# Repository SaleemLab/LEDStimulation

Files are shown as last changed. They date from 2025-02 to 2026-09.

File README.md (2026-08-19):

# Full-Field LED Visual Stimulator

An open-source, high-precision visual stimulation platform designed for visual neuroscience, sensory physiology, and human psychophysics. The system delivers temporally agile, multi-chromatic optical stimulation (e.g., Green for M-cones/rods and UV for S-cones, or custom multi-spectral arrays) with sub-millisecond precision.

https://github.com/user-attachments/assets/08af2269-a270-4899-ae75-62786a714254

*Example stimulus: 2 Hz antiphase (Green / UV) sinusoidal flicker.*

---

## Key Capabilities

- **High-Resolution Temporal Modulation:** 16-bit Phase-Correct carrier PWM (~7.68–10 kHz) combined with hardware-interrupt pacing (Timer3 CTC ISR) eliminates visible digital stepping and software loop jitter.
- **Rich Stimulus Battery:** Native microsecond-timed generation of sinusoidal flickers, Gaussian white noise (with Central Limit Theorem PRNG), contrast-switching adaptation sequences, exponential frequency chirps, and stepped luminance pulses.
- **Quantitative Radiometric Calibration:** End-to-end MATLAB calibration pipeline mapping raw duty cycles to linearized lookup tables (LUTs) and calculating exact photoreceptor isomerisation rates ($R^*/\text{photoreceptor/s}$).
- **Flexible Form Factors:** Supports both 200mm full-field panel enclosures (with magnetic diffusion clamping) and miniature wearable mounts for Pupil Labs Neon eye-tracking glasses.
- **Reactive Experiment Orchestration:** Full integration with [Bonsai](https://bonsai-rx.org/) for closed-loop, state-dependent, adaptive psychometric staircase, and LabStreamingLayer (LSL) multi-modal recording.

---

## System Architecture

```mermaid
graph LR
    subgraph Host Software
        Bonsai[Bonsai Reactive Workflows]
        LSL[LabStreamingLayer / LabRecorder]
        MATLAB[MATLAB Calibration Suite]
    end

    subgraph Microcontroller Firmware
        MCU[Arduino Leonardo / Teensy 4.1]
        T1[Timer1: 16-bit PWM]
        T3[Timer3: CTC Interrupt Pacing]
        LUT[PROGMEM Gamma LUT]
    end

    subgraph Hardware & Optics
        Driver[Multi-Channel Driver Stage]
        LEDs[Dual-Channel LED Arrays]
        Enclosure[Magnetic Diffusion Enclosure / Glasses]
        Sensors[Photodiode / Power Meter / Eye Tracker]
    end

    Bonsai -- Serial ASCII (115200) --> MCU
    MATLAB -. Offline Calibration .-> LUT
    MCU --> T1 & T3
    T3 --> LUT --> T1
    T1 --> Driver --> LEDs --> Enclosure
    Enclosure -. Optical Feedback .-> Sensors
    Sensors --> LSL
```

---

## Quickstart Guide

### 1. Flash the Firmware
1. Open [`ArduinoCode/StimulusControlViaSerial_Leonardo_v8/StimulusControlViaSerial_Leonardo_v8.ino`](file:///d:/Code/LEDStimulation/ArduinoCode/StimulusControlViaSerial_Leonardo_v8/StimulusControlViaSerial_Leonardo_v8.ino) in the Arduino IDE.
2. Select **Arduino Leonardo** as your board and choose the corresponding COM port.
3. Click **Upload**.

### 2. Connect Hardware & Verify
1. Connect your LED driver to the designated MCU pins (PWM: Pins 9 & 10; Indicators: Pins 4 & 5).
2. Open the Serial Monitor at `115200` baud.
3. Send a test sinusoidal flicker:
   ```text
   s, 3000, 2.0, 0.0, 0.5, 0.8, 0.8
   ```
   *(Runs a 3-second, 2 Hz antiphase flicker on Channels A and B at 80% contrast).*

### 3. Launch Experimental Workflows
Open [Bonsai](https://bonsai-rx.org/) and load one of the pre-built visual stimulation workflows from [`BonsaiCode/`](file:///d:/Code/LEDStimulation/BonsaiCode/) (e.g., `LEDstimulation_normal.bonsai` or `ManualMethodOfAdjustment.bonsai`).

---

## Documentation Index

Comprehensive guides, schematics, and technical specifications are available in the **[`docs/`](docs/index.md)** directory:

| Section | Description |
| :--- | :--- |
| **[1. Hardware](docs/1-hardware/circuit-and-driver.md)** | [Circuit & Driver](docs/1-hardware/circuit-and-driver.md) • [Custom PCBs](docs/1-hardware/custom-pcbs.md) • [Panel Enclosure](docs/1-hardware/enclosure-and-optics/panel-enclosure.md) • [Wearable Glasses](docs/1-hardware/enclosure-and-optics/wearable-glasses.md) • [Bill of Materials](docs/1-hardware/bill-of-materials.md) |
| **[2. Firmware](docs/2-firmware/architecture-and-timers.md)** | [Architecture & Hardware Timers](docs/2-firmware/architecture-and-timers.md) • [Serial API Reference](docs/2-firmware/serial-api-reference.md) • [Firmware Variants](docs/2-firmware/firmware-variants.md) |
| **[3. Calibration](docs/3-calibration/calibration-guide.md)** | [Calibration Guide](docs/3-calibration/calibration-guide.md) • [Gamma LUT Pipeline](docs/3-calibration/gamma-lut-pipeline.md) • [Photoreceptor Calculations](docs/3-calibration/photoreceptor-calculations.md) |
| **[4. Experimental Workflows](docs/4-experimental-workflows/bonsai-overview.md)** | [Bonsai Setup](docs/4-experimental-workflows/bonsai-overview.md) • [Stimulation Paradigms](docs/4-experimental-workflows/stimulation-paradigms.md) • [Integration & Multi-Modal Sync](docs/4-experimental-workflows/integration-and-sync.md) |
| **[5. Reference](docs/5-reference/performance-and-sync.md)** | [Performance Characteristics, Switching Dynamics & Thermal Notes](docs/5-reference/performance-and-sync.md) |

---

## Repository Structure

```text
├── ArduinoCode/                  # Microcontroller firmware (Leonardo v8, DDS, Teensy 4.1, IMU)
├── BonsaiCode/                   # Main Bonsai visual reactive workflows & stimulus CSVs
├── BonsaiForHumanExperiments/    # Dedicated human psychophysics Bonsai workflows
├── Calibration/                  # MATLAB scripts for radiometry, gamma LUTs & opsin calculations
├── Hardware/                     # CAD files (.stp, .stl, .ipt), KiCad PCB designs & driver schematics
│   ├── Enclosure/                # Baseplate CAD & 3D printed magnetic diffusion clamps
│   ├── glasses/                  # Pupil Labs Neon glasses boom arm & miniature diffuser
│   ├── LED_board/                # KiCad dual-channel LED array PCB
│   └── LED_board_humans/         # KiCad 3-colour LED array PCB (WIP redesign with layout improvements)
├── HumanExpAnalysis/             # MATLAB scripts for IMU movement and behavioural analysis
├── LabRecorderFiles/             # Multi-modal LabStreamingLayer (LSL) recording configurations
└── docs/                         # Modular technical documentation
```

---

## License & Attribution

Developed for scientific research applications. If you use this platform in your research, please cite this repository.

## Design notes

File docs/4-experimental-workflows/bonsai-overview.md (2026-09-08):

# Bonsai Workflow Overview

[Bonsai](https://bonsai-rx.org/) is an open-source visual reactive programming environment used here to coordinate experiment state, stream serial commands to the microcontroller, record behavioural sensors, and synchronize multi-modal data streams.

!!! note "Work in Progress"
    This documentation section is currently a work in progress.

---

## 1. Environment Setup

* **Bonsai Version:** Compatible with Bonsai 2.7.x / 2.8.x.
* **Required Package Dependencies:**
  * `Bonsai.Core` & `Bonsai.Design`
  * `Bonsai.System` (IO & Serial Ports)
  * `Bonsai.Arduino`
  * `Bonsai.Dsp` & `Bonsai.Numerics`
  * `Bonsai.Shaders` / `Bonsai.Vision` *(for display/camera workflows)*
  * `Bonsai.LabStreamingLayer` *(for LSL multi-modal stream synchronization)*

---

## 2. Solution Structure

Located in [`BonsaiCode/`](file:///d:/Code/LEDStimulation/BonsaiCode/):
* `BonsaiCode.sln` / `Extensions.csproj` — C# extensions for custom Bonsai data processing nodes.
* `.bonsai/` — Package configuration and local environment dependencies.
* `*.bonsai` & `*.bonsai.layout` — Visual workflow definitions and GUI layout arrangements.
* `StimulusCSVfiles/` — Pre-defined stimulus parameter tables and trial condition matrices.

---

## 3. Core Workflow Architecture

```mermaid
flowchart TD
    subgraph TX["1. Stimulus Command Generation & Dispatch"]
        direction LR
        Timer["<b>Trial Trigger</b><br/>Timer or Sync Pulse"]
        Select["<b>Trial Matrix</b><br/>Row from CSV Table"]
        Format["<b>ASCII Formatter</b><br/>Format Serial String"]
        Write["<b>Bonsai SerialPort</b><br/>Non-blocking Dispatch"]
        Timer --> Select --> Format --> Write
    end

    subgraph RX["2. Device Execution & Data Recording"]
        direction LR
        USB["<b>MCU Execution</b><br/>ATmega32U4 / Teensy"]
        Read["<b>Serial Feedback</b><br/>Status / Confirmation"]
        Log["<b>Data Acquisition</b><br/>CSV / LSL Log Streams"]
        USB --> Read --> Log
    end

    Write ==>|Serial ASCII (115200)| USB
```

* **Serial Communication Node:** Configured for the microcontroller's COM port at `115200` baud.
* **Non-Blocking Execution:** Serial commands are dispatched asynchronously, allowing the host PC to continuously stream eye-tracking video, IMU data, or digital sync markers without dropped frames.

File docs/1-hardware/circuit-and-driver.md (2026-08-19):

# Circuit & Driver Design

This section describes the electronic drive circuitry used to power and modulate the optical LED loads in the stimulator.

!!! note "Single-Channel vs. Multi-Channel Scaling"
    The schematics below illustrate the driver circuit for **a single optical channel / colour**. To drive multi-channel systems (e.g., dual-colour or 3-colour arrays), **replicate the circuit for each channel**, connecting each to an independent microcontroller PWM pin (e.g., separate timer outputs). All channels share the common power rails ($+12\,\text{V}$ and GND), while their switching paths and PWM control lines remain independent.

---

## 1. Direct Microcontroller PWM Drive (Base Configuration)

The simplest driving topology connects a single microcontroller PWM output pin directly to an LED load through a series combination of a fixed current-limiting resistor and a multi-turn cermet variable resistor. This direct-drive topology works when the LED load has voltage ($V_f$) and current ($I_{\text{LED}}$) requirements that fall *well* within the direct drive capability of the microcontroller GPIO pins (typically $V_{\text{pin}} \le 5\text{V}$, $I_{\text{max}} \le 20\text{--}40\text{ mA}$).

Simple Direct PWM LED Circuit

* **`PWM Source`:** Outputs a high-frequency PWM carrier providing temporal stimulus patterns for one channel (replicate circuit and use additional PWM pins for multi-colour setups).
* **$R_{\text{fixed}}$ (Current Limiter):** Sets the absolute maximum current ceiling to protect both the microcontroller output pin and LED load from overcurrent when $R_{\text{var}} = 0\,\Omega$.
* **$R_{\text{var}}$ (Cermet Trimpot):** Allows manual analog adjustment of maximum forward current and luminance. Using a **cermet** (ceramic-metal thick-film) trimpot is critical for high-frequency PWM visual stimulation. Alternative potentiometer constructions will degrade or disrupt the stimulus.

---

## 2. Low-Side NPN Transistor Switching Drive (12V / Multi-LED Arrays)

When driving multi-LED series strings or larger arrays that exceed microcontroller GPIO limits ($5\,\text{V}$ and $20\text{--}40\,\text{mA}$), an external DC power supply (typically $+12\,\text{V}$) is used with a low-side NPN bipolar junction transistor (BJT) switch.

Low-Side Transistor LED Circuit

*Figure: Low-side switching circuit for a single colour channel. For multi-channel arrays, replicate the transistor, base resistor, trimpot, and LED strings for each channel while sharing the $+12\,\text{V}$ rail and Common Ground.*

* **`+12V Supply` & Multiple LED Lines:** Powers one or more parallel lines of 3 series LEDs ($V_f \approx 6.3\text{--}9.9\,\text{V}$ per string), leaving optimal voltage headroom from the $12\,\text{V}$ rail.
* **$R_{\text{fixed}}$ (Per-Line Current Limiter):** Each parallel LED line includes its own fixed series resistor to limit and balance current across individual branches.
* **$R_{\text{var}}$ (Master Cermet Trimpot):** A single shared cermet trimpot on the merged return path controls the maximum current and luminance for all parallel lines belonging to **this channel**.
* **NPN Transistor (Low-Side Switch):** General-purpose small-signal NPN transistor (e.g., **onsemi 2N3904**, rated for $40\,\text{V}$, $200\,\text{mA}$, 3-pin TO-92 package). Sinks the combined load current for this channel to ground when switched ON by the PWM signal (ensure total channel current across parallel strings remains $\le 200\,\text{mA}$).
* **`PWM Source`, $R_{\text{base}}$ & $R_{\text{pull-down}}$:** An MCU PWM pin switches the transistor through a base resistor ($R_{\text{base}} \approx 100\,\Omega$). A pull-down resistor ($R_{\text{pull-down}} = 10\,\text{k}\Omega$) keeps the base pulled to $0\,\text{V}$ during microcontroller startup or floating states.
* **Common Ground:** The Arduino ground and the external $12\,\text{V}$ power supply ground **must be connected together** to establish the shared $0\,\text{V}$ reference required for the base-emitter voltage ($V_{BE} \approx 0.7\,\text{V}$) to switch the transistor reliably.
* **Multi-Channel Operation:** To drive a 2nd or 3rd colour channel independently, duplicate the transistor stage ($Q_1, R_{\text{base}}, R_{\text{var}}$) and connect its base to a 2nd MCU PWM pin (e.g. Pin 9 and Pin 10 on Arduino Uno / Nano). All channels share the $+12\,\text{V}$ power rail and system Ground.

---

## 3. Physical Circuit & Bench Implementation

Physical Circuit Bench Setup
*Figure: Benchtop driver circuit implementation showing Arduino microcontroller, multi-turn cermet trimpot, transistor switching stage, and wiring harness connected to LED array.*

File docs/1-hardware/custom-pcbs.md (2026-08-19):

# Custom PCBs

This page documents the custom PCBs designed in KiCad for multi-wavelength LED stimulation and driver interfacing.

---

## 1. Standard LED Array Board (`LED_board`)

* **Location:** [`Hardware/LED_board/`](file:///d:/Code/LEDStimulation/Hardware/LED_board/) | **Status:** **Active**
* **Files:** `LED_board.kicad_sch`, `LED_board.kicad_pcb`, `LED_board.step`, `production/`
* **Acknowledgements:** Board is based on an earlier prototype designed by Andre Maia Chagas.

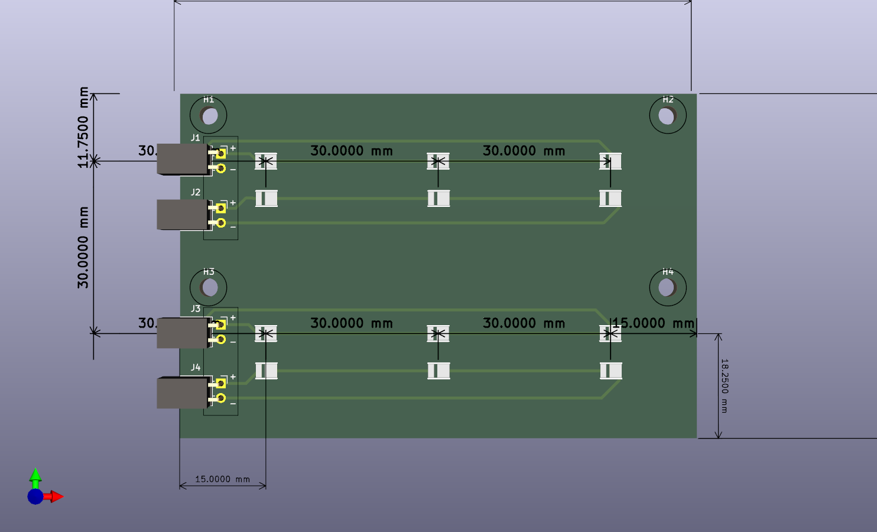
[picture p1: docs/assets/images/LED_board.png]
Standard LED Array Board Render

*Figure: KiCad 3D layout of standard dual-channel LED array board with dimensions and grid pitch.*

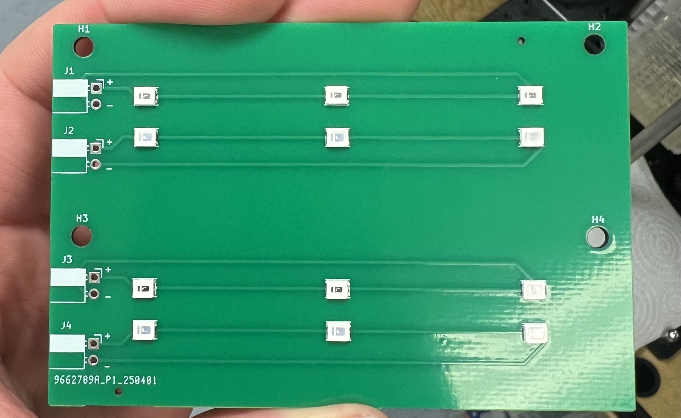
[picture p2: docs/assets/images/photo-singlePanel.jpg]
Single Assembled PCB

*Figure: Assembled dual-channel LED array PCB showing the 4 LED lines, solder pads for J1–J4, and mounting holes H1–H4.*

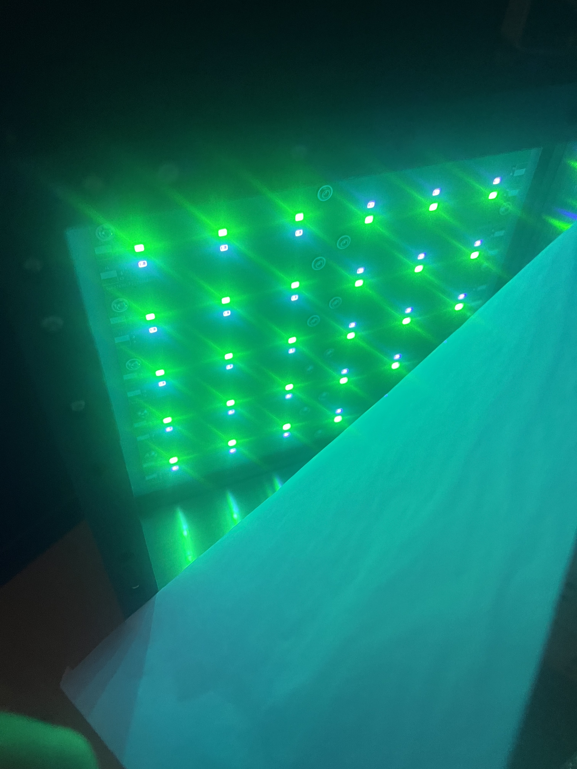
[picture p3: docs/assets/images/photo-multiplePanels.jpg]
Multiple Tiled Panels in Operation

*Figure: Multiple tiled LED boards mounted inside the panel enclosure and illuminated beneath the optical diffuser sheet.*

### Design & Current Implementation

The board provides wide-field visual stimulation using multiple equally-spaced LED lines:

* **Layout:** 4 lines of LEDs (2 lines per colour, interleaved), with 3 series LEDs per line (12 LEDs total, running at $+12\,\text{V}$).
* **Spacing:** $3\,\text{cm}$ ($30\,\text{mm}$) pitch between lines, matching the spacing across adjacent tiled boards.
* **Mounting:** Through-holes for M3 standoffs to attach securely to the aluminium backplate / heatsink.
* **Connectors:** 4 separate 2-pin ($2.54\,\text{mm}$) headers — one dedicated connector per LED line (8 wires total per board back to the driver). Headers can be straight or right-angled, and can be mounted on the **front or reverse side** of the PCB to route cables cleanly out the back of the backplate.
* **Current Limiting:** External (requires off-board resistors on the driver board).

### Future Improvements

* **On-Board SMD Resistors:** Add dedicated surface-mount ballast resistors (1206 footprint) on each line to balance branch currents directly on the PCB and eliminate off-board resistors.
* **Single Consolidated Connector:** Replace the 4 separate 2-pin headers with a single multi-pin connector (e.g. 4-pin JST-XH). A common $+12\,\text{V}$ anode rail powers all lines, branching into separate low-side return paths per colour for independent PWM modulation (reducing wiring from 8 to 3–4 wires).
* **Modular Daisy-Chaining:** Add pass-through edge connectors so arbitrary boards can be tiled together with parallel electrical connections, preserving the $3\,\text{cm}$ pitch without extra cable runs.

---

## 2. Experimental & In-Development Boards

### 3-Colour LED Array Board (`LED_board_humans`)
* **Location:** [`Hardware/LED_board_humans/`](file:///d:/Code/LEDStimulation/Hardware/LED_board_humans/) | **Status:** ⚠️ **WIP**
* Experimental 3-channel (3-colour) panel redesign with optimized routing. *(Note: Unrelated to the wearable glasses setup).*

### Constant Current Driver Board (`Constant_current_driver`)
* **Location:** [`Hardware/Constant_current_driver/`](file:///d:/Code/LEDStimulation/Hardware/Constant_current_driver/) | **Status:** ⚠️ **WIP (Inactive)**
* Prototype driver board. Current setups use the low-side transistor circuit described in [Circuit & Driver Design](file:///d:/Code/LEDStimulation/docs/1-hardware/circuit-and-driver.md).

---

## 3. Fabrication

Gerber files and drill maps are in the respective `production/` directories, ready for fabrication (e.g. JLCPCB, PCBWay).

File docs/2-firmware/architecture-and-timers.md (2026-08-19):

# Firmware Architecture & System Principles

The visual stimulation platform utilizes bare-metal microcontroller firmware to deliver sub-millisecond temporal precision, high carrier frequencies, and artifact-free luminance modulation.

We use primarily the **Arduino Leonardo (ATmega32U4 @ 16 MHz)**, which possesses several hardware properties that make it well suited for high-precision optical stimulation:

* **Native USB Communication (CDC):** The ATmega32U4 features native on-chip USB communication, avoiding the transfer latency, buffer bloat, and jitter introduced by external USB-to-UART bridge chips (e.g., FTDI / CH340).
* **Deterministic 16-bit Timer Registers:** Direct bare-metal control of hardware `Timer1` allows 31.25 kHz Phase Correct PWM with cycle-accurate register writes (`OCR1A`, `OCR1B`).
* **Sub-Microsecond Timing Determinism:** Without an underlying RTOS or thread scheduler, interrupt service routines execute with sub-microsecond predictability.
* **Cost & Accessibility:** Standardized, open-source form factor that is cost-effective and readily replicable across research laboratories.

Other microcontrollers can also be used if higher bit-depth, clock speed, or sample rates are desired—such as the **PJRC Teensy 4.1 (ARM Cortex-M7 @ 600 MHz)**, for which a 12-bit, 36.62 kHz DDS implementation ([`LEDStimController_Teensy41_DDS.ino`](file:///d:/Code/LEDStimulation/ArduinoCode/LEDStimController_Teensy41_DDS/LEDStimController_Teensy41_DDS.ino)) is provided.

The primary canonical firmware is **[`StimulusControlViaSerial_Leonardo_DDS_8bit_2freq.ino`](file:///d:/Code/LEDStimulation/ArduinoCode/StimulusControlViaSerial_Leonardo_DDS_8bit_2freq/StimulusControlViaSerial_Leonardo_DDS_8bit_2freq.ino)**, implementing a **Direct Digital Synthesis (DDS)** engine running at a **31.25 kHz** carrier frequency.

---

## 1. Canonical System Architecture (`DDS_8bit_2freq`)

The canonical firmware synchronizes carrier PWM generation and stimulus waveform synthesis at **31.25 kHz** using Direct Digital Synthesis (DDS).

* **Command Ingestion:** ASCII commands received over USB Serial at 115200 baud are parsed and configured into stimulus state parameters (frequencies, phases, contrasts, durations).
* **High-Frequency Carrier:** Hardware `Timer1` generates a 31.25 kHz Phase Correct PWM carrier on Pin 9 (Channel A) and Pin 10 (Channel B).
* **Synchronous Interrupt Pacing:** The `TIMER1_OVF_vect` interrupt fires synchronously on every PWM cycle at 31.25 kHz ($32\ \mu\text{s}$ period), invoking a dynamic callback function pointer (`timer1Callback`).
* **DDS Waveform Synthesis:** The 32-bit phase accumulators advance each cycle, indexing into a 256-sample sine wavetable, and applying raised cosine onset/offset envelopes or contrast envelopes.
* **Optical Linearization:** The calculated luminance index is mapped through Flash-resident (`PROGMEM`) gamma Look-Up Tables before being written directly to `OCR1A` and `OCR1B`.

---

## 2. Core Architectural Principles

### 2.1. Direct Digital Synthesis (DDS) Engine

Rather than stepping through a wavetable with variable timer interrupts, the DDS engine uses **32-bit fixed-point phase accumulators** updated at every single PWM carrier cycle ($31.25\text{ kHz}$):

$$\Delta\theta = \text{round}\left(f_{\text{stimulus}} \times \frac{2^{32}}{f_{\text{PWM}}}\right)$$

On an ATmega32U4 running at 16 MHz with a $31.25\text{ kHz}$ PWM carrier, the scaling constant is pre-computed with IEEE 754 precision:

$$\frac{2^{32}}{31250} = 137438.953125$$

```cpp
uint32_t calcPhaseInc(float freq) {
    // 4294967296.0 / 31250.0 = 137438.953125
    return (uint32_t)(freq * 137438.953125f + 0.5f);
}
```

* **Instantaneous Frequency & Phase Transitions:** Frequency changes require simply writing a new 32-bit phase increment value (`phaseIncrementA = calcPhaseInc(newFreq)`). There are zero phase discontinuities, zero timer reconfiguration delays, and no waveform glitches.
* **Wavetable Indexing:** The most significant byte of the 32-bit accumulator directly selects the sample from a 256-point sinusoidal wavetable:
  ```cpp
  uint8_t indexA = ((uint8_t*)&phaseAccumulatorA)[3]; // Instantaneous byte extraction
  ```

---

### 2.2. High-Frequency Carrier Generation & Timer1 PWM Configuration

`Timer1` on the ATmega32U4 is configured in **16-bit Phase Correct PWM mode (Mode 10)**. In this dual-slope mode, the timer counts continuously up from $0$ to `ICR1` (TOP) and then counts down from `ICR1` back to $0$.

The resulting PWM carrier frequency is given by:

$$f_{\text{PWM}} = \frac{f_{\text{CPU}}}{2 \times N \times \text{TOP}}$$

For a target frequency of $31.25\text{ kHz}$ with a $16\text{ MHz}$ CPU clock, the prescaler is $N = 1$ and $\text{TOP} = 256$:

$$f_{\text{PWM}} = \frac{16\text{ MHz}}{2 \times 1 \times 256} = 31.25\text{ kHz}$$

* **Elimination of Saccadic CFF Artifacts:** The Critical Flicker Fusion (CFF) threshold in rodents and primates is typically $< 60-100\text{ Hz}$. Operating at $31.25\text{ kHz}$ guarantees that rapid eye movements or micro-saccades can never visually resolve carrier switching.
* **Photodiode & Recording Immunity:** High-speed electrophysiological amplifiers and photodiodes are immune to carrier ringing at $31.25\text{ kHz}$.
* **Acoustic Silence:** Prevents audible coil whine from inductors or ceramic capacitors in the driver circuitry.

#### Step 1: Calculating Prescaler and TOP

The firmware calculates the optimal prescaler ($N \in \{1, 8, 64, 256, 1024\}$) and `TOP` value dynamically to maximize bit-depth resolution:

```cpp
long calculatePrescalerAndTOP(long desiredFrequency, long &prescaler) {
  long TOP = 0;
  long possiblePrescalers[] = { 1, 8, 64, 256, 1024 };

  for (int i = 0; i < 5; i++) {
    long currentPrescaler = possiblePrescalers[i];
    long calculatedTOP = (CLOCK_FREQ / (2 * currentPrescaler * desiredFrequency));

    if (calculatedTOP >= 0 && calculatedTOP <= 65535) {
      prescaler = currentPrescaler;
      TOP = calculatedTOP;
      break;  // Select the smallest valid prescaler for maximum resolution
    }
  }
  return TOP;
}
```

For $31250\text{ Hz}$, the algorithm selects `prescaler = 1` and `TOP = 256` ($8\text{-bit}$ resolution).

#### Step 2: Register-Level Timer1 Setup

The `configureTimer1()` function directly writes to the ATmega32U4 control registers (`TCCR1A`, `TCCR1B`, `ICR1`):

```cpp
void configureTimer1(long prescaler, long TOP) {
  // Reset Timer1 control registers
  TCCR1A = 0;
  TCCR1B = 0;

  // Enable non-inverting PWM output on Pin 9 (OC1A) and Pin 10 (OC1B)
  TCCR1A |= (1 << COM1A1);  
  TCCR1A |= (1 << COM1B1);  

  // Configure Phase Correct PWM with ICR1 as TOP (Mode 10)
  TCCR1B |= (1 << WGM13);   
  TCCR1B &= ~(1 << WGM12);  
  TCCR1A &= ~(1 << WGM11);  
  TCCR1A &= ~(1 << WGM10);  

  // Apply clock prescaler
  switch (prescaler) {
    case 1:    TCCR1B |= (1 << CS10); break;               // Prescaler = 1 (No division)
    case 8:    TCCR1B |= (1 << CS11); break;               // Prescaler = 8
    case 64:   TCCR1B |= (1 << CS11) | (1 << CS10); break; // Prescaler = 64
    case 256:  TCCR1B |= (1 << CS12); break;               // Prescaler = 256
    case 1024: TCCR1B |= (1 << CS12) | (1 << CS10); break; // Prescaler = 1024
  }

  // Set the TOP counter limit (ICR1 = 256)
  ICR1 = TOP;
}
```

* `COM1A1` & `COM1B1`: Enable non-inverting compare mode on OC1A (Pin 9) and OC1B (Pin 10). The pin clears on compare match when counting up, and sets on compare match when counting down.
* `WGM13 = 1` (with `WGM12=0`, `WGM11=0`, `WGM10=0`): Sets dual-slope Phase Correct PWM with `ICR1` acting as the TOP limit.
* `CS10 = 1`: Connects the 16 MHz system clock directly without prescaling ($N=1$).
* `ICR1 = 256`: Establishes the peak counter value.

#### Step 3: Fast Inline Output Writes

Luminance duty cycles are updated by writing directly to `OCR1A` and `OCR1B`, reading calibrated values from `PROGMEM` Flash tables:

```cpp
__attribute__((always_inline)) inline void setChA(uint8_t ocrValue) {
  OCR1A = pgm_read_byte_near(currentChALUT + ocrValue);
}

__attribute__((always_inline)) inline void setChB(uint8_t ocrValue) {
  OCR1B = pgm_read_byte_near(currentChBLUT + ocrValue);
}
```

#### Step 4: Synchronous Interrupt Coupling (`TIMER1_OVF_vect`)

In Phase Correct PWM mode, the timer overflow interrupt flag (`TOV1`) is set every time the counter reaches bottom ($0$). The firmware uses this interrupt to synchronously trigger the DDS waveform synthesis at $31.25\text{ kHz}$:

```cpp
void (*timer1Callback)() = nullptr;  

void setTimer1Callback(void (*callback)()) {
  timer1Callback = callback;
}

void startTimer1Interrupt() {
  TIFR1 |= (1 << TOV1);     // Clear any pending overflow flag
  TIMSK1 |= (1 << TOIE1);   // Enable Timer1 Overflow Interrupt
}

void stopTimer1Interrupt() {
  TIMSK1 &= ~(1 << TOIE1);  // Disable Timer1 Overflow Interrupt
}

ISR(TIMER1_OVF_vect) {
  if (timer1Callback) {
    timer1Callback();       // Executes DDS synthesis at 31.25 kHz
  }
}
```

---

### 2.3. Dual Independent Channels & Frequencies

`StimulusControlViaSerial_Leonardo_DDS_8bit_2freq` maintains independent 32-bit phase accumulators and phase increments for Channel A and Channel B:

* **Dichoptic Stimulation:** Present distinct frequencies simultaneously to each eye (e.g., $5\text{ Hz}$ on Left Eye, $7\text{ Hz}$ on Right Eye).
* **Chromatic & Dual-Wavelength Probing:** Drive Green ($530\text{ nm}$) and UV ($395\text{ nm}$) LEDs with independent phase relationships ($0^\circ$ in-phase vs. $180^\circ$ antiphase) and independent contrast levels.

---

### 2.4. Raised Cosine Temporal Windowing (Fade In/Out)

Sudden rectangular onsets of bright visual flicker can trigger retinal startle responses and severe transient visual evoked potentials (VEPs).

The firmware applies a smooth **Modular Raised Cosine Temporal Window** (default $100\text{ ms}$):

* A 64-entry pre-computed envelope table (`raisedCosineLUT[64]`) scales the contrast from $0 \to 100\%$ at stimulus onset and $100\% \to 0$ at stimulus offset.
* A 32-bit addition accumulator (`fadePhase += envStep`) steps through the envelope table without runtime multiplication or floating-point trigonometry.

---

### 2.5. Jitter Elimination & USB Heartbeat Suppression

Under normal Arduino operation, the USB Start-of-Frame (SOF) interrupt fires every $1.0\text{ ms}$, and `Timer0` fires every $1.024\text{ ms}$ for `millis()`. These interrupts cause microsecond-scale jitter and cumulative timing drift ($\approx 10.5\text{ ms}$ slip over long trials).

During active stimulation, the firmware temporarily suppresses these interrupts:

```cpp
TIMSK0 &= ~_BV(TOIE0);  // Disable Timer0 millis() interrupt
UDIEN &= ~(1 << SOFE);  // Disable USB Start-of-Frame interrupt
```

Upon trial completion, both interrupts are re-enabled, ensuring zero timing slip during stimulation while retaining full USB communication.

---

### 2.6. Lock-Free Atomic Synchronization

To avoid global interrupt blocking (`cli()` / `sei()`) that could introduce carrier jitter, the firmware uses a double-read atomic pattern to safely read multi-byte cycle counters between the main loop and ISR:

```cpp
uint32_t safeCycles1, safeCycles2;
do {
    safeCycles1 = completedCycles;
    safeCycles2 = completedCycles;
} while (safeCycles1 != safeCycles2);
```

---

## 3. Sinewave Trial Execution Lifecycle (End-to-End Walkthrough)

When host software (e.g. Bonsai or Python) requests a sinusoidal flicker trial, the firmware executes a precise sequence across serial ingestion, parameter arming, interrupt-driven synthesis, and completion handshake.

```
[Host PC]  -- "s,5000,4.0,4.0,0.0,0.5,0.8,0.8\r" -->  [Serial Parser]
                                                              |
                                                    [outputSinewave()]
                                                    (Arm DDS, Phase, Fade)
                                                              |
                                            [Disable Timer0 & USB SOF]
                                            [Attach Timer1 OVF Callback]
                                                              |
                                          [31.25 kHz sinewaveInterrupt()]
                                          (DDS step, Fade, LUT, OCR1A/B)
                                                              |
                                           [Target Interrupts Reached]
                                                              |
                                            [Restore Interrupts & Pins]
[Host PC]  <------------- "-1\n" Handshake ----------- [Serial Print]
```

### Step 1: Serial Command Ingestion & Parsing

The main `loop()` continuously monitors incoming characters over USB CDC:

```cpp
void loop() {
  GetSerialInput();
  if (newData) {
    newData = false;
    ActionSerial();
  }
}
```

When a carriage return (`\r`) is received, `ActionSerial()` tokenizes the comma-separated ASCII string:

```cpp
// Example input: "s, 5000, 4.0, 4.0, 0.0, 0.5, 0.8, 0.8"
if (strcmp(FirstChar, "s") == 0) {
  long stimulusDuration = atof(serialVals[1]); // Duration (ms)
  float freqA = atof(serialVals[2]);           // Channel A Frequency (Hz)
  float freqB = atof(serialVals[3]);           // Channel B Frequency (Hz)
  float phaseA = atof(serialVals[4]);         // Channel A Starting Phase (0.0-1.0)
  float phaseB = atof(serialVals[5]);         // Channel B Starting Phase (0.0-1.0)
  float contrastA = atof(serialVals[6]);      // Channel A Contrast (0.0-1.0)
  float contrastB = atof(serialVals[7]);      // Channel B Contrast (0.0-1.0)

  outputSinewave(freqA, freqB, stimulusDuration, phaseA, phaseB, contrastA, contrastB);
}
```

---

### Step 2: Pre-Computing Trial Parameters & Arming the Hardware

Inside `outputSinewave()`, parameters are converted into fast integer representations before starting interrupts:

```cpp
void outputSinewave(float freqA, float freqB, long duration, float phaseA, float phaseB, float contrastA, float contrastB) {
  // 1. Convert phase offsets (0.0-1.0) to full 32-bit phase accumulator starting values
  phaseAccumulatorA = (uint32_t)(phaseA * 4294967296.0);
  phaseAccumulatorB = (uint32_t)(phaseB * 4294967296.0);

  // 2. Scale contrast floats (0.0-1.0) to 8-bit integer multipliers (0-255)
  contrastMultIntA = (uint16_t)(contrastA * 255.0);
  contrastMultIntB = (uint16_t)(contrastB * 255.0);

  // 3. Compute 32-bit DDS phase increments for both channels
  phaseIncrementA = calcPhaseInc(freqA);
  phaseIncrementB = calcPhaseInc(freqB);

  // 4. Calculate total PWM carrier cycles required for the requested trial duration
  targetTotalInterrupts = (unsigned long)((duration / 1000.0) * actualPWMFreq);

  // 5. Configure the 100ms Raised Cosine onset and offset fade boundaries
  float fadeTimeMs = FADE_DURATION_MS;
  if (fadeTimeMs > 0.0) {
    fadeInterrupts = (unsigned long)(actualPWMFreq * (fadeTimeMs / 1000.0));
    fadeOutStartInterrupt = targetTotalInterrupts - fadeInterrupts;
    envStep = (((uint32_t)FADE_LUT_MAX << 16) + fadeInterrupts - 1) / fadeInterrupts;
  }

  currentTick = 0;
  completedCycles = 0;
  fadePhase = 0;
  stimulusActive = true;

  // 6. Set channels to baseline mid-luminance (50% duty cycle)
  if (useChA) { setChA(MidLumi); }
  if (useChB) { setChB(MidLumi); }

  // 7. Drive hardware indicator pins HIGH (Pin 5 = Stimulus ON, Pin 4 = Frame/Cycle indicator)
  PORTC |= (1 << PORTC6); // Pin 5 HIGH
  PORTD |= (1 << PIND4);  // Pin 4 HIGH

  // 8. Temporarily disable Timer0 and USB SOF interrupts to prevent microsecond jitter
  TIMSK0 &= ~_BV(TOIE0);
  UDIEN &= ~(1 << SOFE);

  // 9. Attach the callback and start the 31.25 kHz Timer1 interrupt
  setTimer1Callback(sinewaveInterrupt);
  startTimer1Interrupt();

  // 10. Jitter-free wait loop (Main loop idles cleanly while ISR drives hardware)
  while (stimulusActive) {
    // Peacefully idle
  }

  // 11. Trial Teardown
  stopTimer1Interrupt();
  TIMSK0 |= _BV(TOIE0);   // Re-enable Timer0
  UDIEN |= (1 << SOFE);   // Re-enable USB SOF

  PORTD &= ~(1 << PIND4); // Pin 4 LOW
  PORTC &= ~(1 << PORTC6); // Pin 5 LOW

  // 12. Reset to baseline and send completion handshake
  if (useChA) { setChA(TopLumi / 2); }
  if (useChB) { setChB(TopLumi / 2); }
  delayMicroseconds(2000);
  Serial.print(F("-1\n"));
}
```

---

### Step 3: Synchronous Waveform Synthesis (`sinewaveInterrupt()` @ 31.25 kHz)

Every $32\ \mu\text{s}$, the Timer1 overflow interrupt triggers `sinewaveInterrupt()`. The entire routine executes in under $4\ \mu\text{s}$ using pure fixed-point arithmetic:

```cpp
void sinewaveInterrupt() {
  uint8_t currentEnvelope = 255;

  // 1. Calculate the active Raised Cosine fade envelope (Onset Ramp vs Steady State vs Offset Ramp)
  if (currentTick < fadeInterrupts) {
    fadePhase += envStep;
    uint16_t envIndex = fadePhase >> 16;
    if (envIndex > FADE_LUT_MAX) envIndex = FADE_LUT_MAX;
    currentEnvelope = raisedCosineLUT[envIndex];
  } else if (currentTick == fadeOutStartInterrupt) {
    fadePhase = 0;
    currentEnvelope = raisedCosineLUT[FADE_LUT_MAX];
  } else if (currentTick > fadeOutStartInterrupt) {
    fadePhase += envStep;
    uint16_t shiftPhase = fadePhase >> 16;
    uint16_t envIndex = (shiftPhase >= FADE_LUT_MAX) ? 0 : (FADE_LUT_MAX - shiftPhase);
    currentEnvelope = raisedCosineLUT[envIndex];
  }

  // 2. Track master elapsed clock and check for trial completion
  currentTick++;
  if (currentTick >= targetTotalInterrupts) {
    stimulusActive = false; // Signals the main loop to exit
  }

  // 3. Modulate requested contrast depth by the temporal envelope
  uint16_t effectiveContrastA = ((uint16_t)contrastMultIntA * (uint16_t)currentEnvelope) >> 8;
  uint16_t effectiveContrastB = ((uint16_t)contrastMultIntB * (uint16_t)currentEnvelope) >> 8;

  // 4. Advance 32-bit phase accumulators by the DDS phase increments
  uint32_t oldPhaseA = phaseAccumulatorA;
  phaseAccumulatorA += phaseIncrementA;
  phaseAccumulatorB += phaseIncrementB;

  // 5. Toggle Pin 4 on full cycle wrap-around to provide hardware cycle tracking
  if (phaseAccumulatorA < oldPhaseA) {
    completedCycles++;
    PIND = (1 << PIND4); // Hardware toggle Pin 4
  }

  // 6. Fast bitwise extraction of high byte for wavetable lookup (256 entries)
  uint8_t indexA = ((uint8_t*)&phaseAccumulatorA)[3];
  uint8_t indexB = ((uint8_t*)&phaseAccumulatorB)[3];

  // 7. Apply contrast depth around MidLumi (50% baseline)
  int16_t tempA = (int16_t)sineWaveTable[indexA] - (int16_t)MidLumi;
  int16_t ocrValA_calc = (int16_t)MidLumi + ((tempA * (int16_t)effectiveContrastA) >> 8);
  if (ocrValA_calc < 0) ocrValA_calc = 0;
  if (ocrValA_calc > 255) ocrValA_calc = 255;
  uint8_t ocrValA = (uint8_t)ocrValA_calc;

  int16_t tempB = (int16_t)sineWaveTable[indexB] - (int16_t)MidLumi;
  int16_t ocrValB_calc = (int16_t)MidLumi + ((tempB * (int16_t)effectiveContrastB) >> 8);
  if (ocrValB_calc < 0) ocrValB_calc = 0;
  if (ocrValB_calc > 255) ocrValB_calc = 255;
  uint8_t ocrValB = (uint8_t)ocrValB_calc;

  // 8. Lookup gamma-corrected register values and write directly to OCR1A and OCR1B
  if (useChA) { setChA(ocrValA); }
  if (useChB) { setChB(ocrValB); }
}
```

---

## 4. Additional Stimulus Engines (from v8 Firmware)

While the DDS firmware is the primary engine for smooth sinusoidal, frequency sweep, and contrast envelope stimulation, the **[`StimulusControlViaSerial_Leonardo_v8.ino`](file:///d:/Code/LEDStimulation/ArduinoCode/StimulusControlViaSerial_Leonardo_v8/StimulusControlViaSerial_Leonardo_v8.ino)** firmware provides specialized stochastic noise stimuli:

```mermaid
graph TD
    v8["StimulusControlViaSerial_Leonardo_v8<br><i>Stochastic Stimulus Engine</i>"]
    
    v8 --> WN["Gaussian White Noise ('wn')<br><i>xorshift32 PRNG + Central Limit Theorem</i>"]
    v8 --> FWN["Frozen White Noise ('fwn')<br><i>Reproducible PRNG Seed & Fixed Buffer</i>"]
    v8 --> CS["Contrast-Switching Noise ('cs')<br><i>2-State Alternating Gaussian Distribution</i>"]
```

### 4.1. Real-Time Gaussian White Noise (`wn`)

* **PRNG Engine (`xorshift32`):** Generates high-entropy 32-bit pseudo-random numbers in just 3 clock cycles.
* **Central Limit Theorem (CLT) Gaussian Approximation:** Instead of computationally heavy Box-Muller transformations, sums $N = 10$ uniform random variables:
    $$
    Z = \frac{\sum_{i=1}^{10} U_i - \mu_{\text{sum}}}{\sigma_{\text{sum}}} \sim \mathcal{N}(0, 1)
    $$
* **Luminance Mapping:** Scales $Z$ by `target_std` and offsets by `target_mean` to produce dynamic Gaussian luminance frames updated at discrete intervals (e.g. $10\text{ ms} = 100\text{ Hz}$).

### 4.2. Frozen White Noise (`fwn`)

* Pre-computes a deterministic Gaussian sequence into an SRAM buffer (`frozenWhiteNoiseTable[375]`) using a specific seed (`randSeedNum`).
* Loops the exact sequence `nReps` times to allow trial-averaged neural response analysis (e.g., Spike-Triggered Averaging / Receptive Field Mapping).

### 4.3. Contrast-Switching Adaptation Noise (`cs`)

* Alternates periodically between two Gaussian distributions (e.g., State 1: 5% contrast vs. State 2: 25% contrast) every `switchTime` ms.
* Used to probe the kinetics of sensory gain control and neural contrast adaptation.

---

## 5. Gamma Linearization & Look-Up Tables

Both firmware variants use Flash-resident (`PROGMEM`) Look-Up Tables to perform real-time optical linearization without runtime floating-point power equations:

```cpp
__attribute__((always_inline)) inline void setChA(uint8_t ocrValue) {
    OCR1A = pgm_read_byte_near(currentChALUT + ocrValue);
}
```

* **Bank Switching (`agc`):** The active LUT bank can be dynamically switched between Bank 1 (linear/identity) and Bank 2 (calibrated empirical gamma curve) via serial command.

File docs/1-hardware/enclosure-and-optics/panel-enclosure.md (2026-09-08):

# Full-Field Panel Enclosure & Optics

The full-field visual stimulator utilizes a modular MakerBeam XL frame, precision aluminium baseplates, and 3D printed magnetic diffusion clamps to achieve spatial uniformity and fast optical filter/diffuser swapping.

---

## Mechanical Assembly

```mermaid
flowchart TD
    subgraph Structure["1. Structural Chassis & Heat Dissipation"]
        direction LR
        Frame["<b>MakerBeam XL Frame</b>"]
        Baseplate["<b>Aluminium Baseplate</b>"]
        PCBs["<b>LED Array PCBs</b>"]
        Frame --> Baseplate --> PCBs
    end

    subgraph Optical["2. Optical Diffusion Stack"]
        direction LR
        DiffBase["<b>Magnetic Diffusion Base</b>"]
        Film["<b>Diffusion Film / Filters</b>"]
        Clamp["<b>Magnetic Top Clamp</b>"]
        DiffBase --> Film --> Clamp
    end

    Structure ==> Optical
```

Full-Field Panel Enclosure Assembly
*Figure: Fully assembled panel enclosure showing MakerBeam XL framework, CNC aluminium baseplate, mounted LED PCBs, and top magnetic diffuser.*

---

## 1. Frame & Baseplate

* **CAD Models:** [`Hardware/Enclosure/`](file:///d:/Code/LEDStimulation/Hardware/Enclosure/)
  * `Baseplate_for_PCBs_v3.stp` / `.ipt` — Master baseplate CAD for CNC milling or laser cutting.
  * `Baseplate_for_PCBs_v3_section.stl` — 3D printable test section.
* **Extrusions:** 15x15mm MakerBeam XL beams (200mm and 50mm lengths) connected via black anodized corner cubes and M3 button-head socket screws.
* **Thermal Management:** The aluminium baseplate serves as an effective heat sink for the LED arrays and driver circuitry.

---

## 2. Magnetic Diffusion Clamping System

To allow rapid changing of diffusion sheets, neutral density filters, or spectral filters without disassembling the chassis:

Magnetic Diffusion Clamps Detail
*Figure: Detail view of 3D-printed magnetic corner and long-edge clamping elements holding the optical diffusion sheet.*

* **Corner Elements:**
  * Base: `box_corner_screws_and_magnets.stl` (Fastens to the MakerBeam frame with M3 hardware and houses 5mm neodymium magnets).
  * Clamp: `box_corner_just_magnets.stl` (Snaps on top to secure the diffusion sheet).
* **Long Edge Elements:**
  * Base: `box_long_edge_screws_and_magnets.stl`
  * Clamp: `box_long_edge_just_magnets.stl`
* **Batch Print Package:** `UM3_all3dprintedparts.3mf` (UltiMaker / Prusa / Bambu 3MF package containing the complete print set).

---

## 3. Optical Considerations

* **Diffusion Distance:** The distance between the LED PCB plane and the diffusion sheet is set by the 50mm vertical MakerBeam extrusion. This was the minimum for sufficient spatial homogenisation of light. 
* **Diffuser Stacking:** Multiple diffusers can be stacked to produce more homogenised light.
* **Filter Stacking:** Optical diffusers (e.g. holographic or engineered diffusers) can be paired with neutral density filters to extend the dynamic range into scotopic regimes, instead/as well as using the trimpots.

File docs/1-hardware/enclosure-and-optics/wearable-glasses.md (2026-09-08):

# Wearable Glasses Setup (Pupil Labs Neon Integration)

For human visual psychophysics, mobile experiments, and simultaneous eye-tracking paradigms, a miniature stimulation and diffusion assembly is mounted directly to the **Pupil Labs Neon** eye-tracking frame.

---

## Hardware & 3D Models

* **CAD Location:** [`Hardware/glasses/`](file:///d:/Code/LEDStimulation/Hardware/glasses/)
* **Key Files:**
  * `boom_arm.stl` / `boom_arm.ipt` — Custom 3D printed boom arm that attaches securely to the Neon eye-tracker frame.
  * `diffuser_fullipt.ipt` — Miniature optical diffuser housing that holds the stimulus LED array in front of the subject's visual field without obstructing the eye camera's gaze-tracking optics.
  * `Neon_JAN_frame_reference/` — Reference frame geometries for fit and alignment validation.

<div style="display: flex; gap: 14px; justify-content: center; align-items: flex-start; margin: 1.5em 0;">
  <div style="flex: 1; max-width: 45%; text-align: center;">
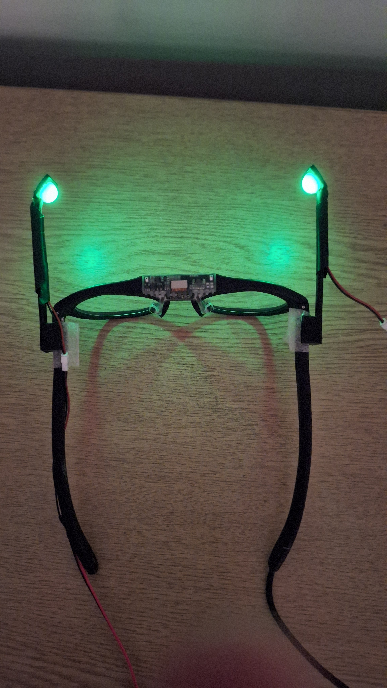
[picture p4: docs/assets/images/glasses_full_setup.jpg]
Wearable Glasses Assembly
    
  </div>
  <div style="flex: 1; max-width: 45%; text-align: center;">
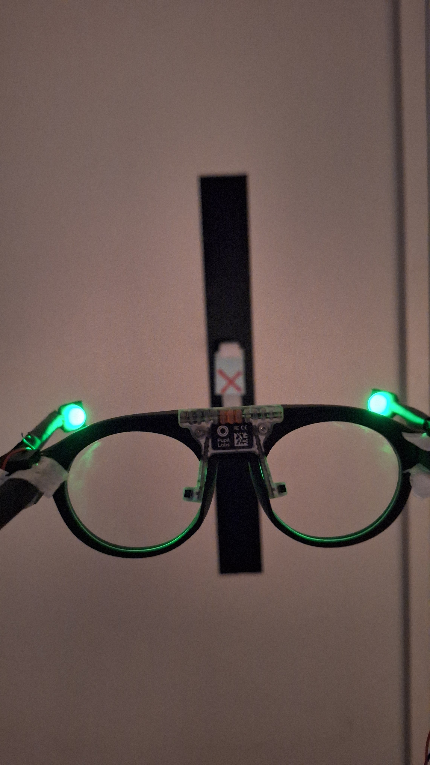
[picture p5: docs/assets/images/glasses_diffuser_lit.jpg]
Illuminated Miniature Diffusers
    
  </div>
</div>
*Figure: Earlier prototype of the wearable stimulation glasses mounted to the Pupil Labs Neon eye-tracking frame. Left: Full frame assembly with boom arms and temple-routed wiring. Right: Close-up of illuminated miniature diffuser domes in front of the visual field without obstructing gaze-tracking cameras.*

---

## Assembly & Alignment

```mermaid
flowchart TD
    subgraph Mechanical["Mechanical Mounting"]
        direction LR
        NeonFrame["<b>Pupil Labs Neon Frame</b>"]
        BoomArm["<b>Custom Boom Arm</b>"]
        DiffuserHousing["<b>Miniature Diffuser Housing</b>"]
        LEDAssembly["<b>Dual-LED Sub-Assembly</b>"]
        NeonFrame --> BoomArm --> DiffuserHousing --> LEDAssembly
    end

    subgraph Optical["Optical Delivery & Tracking"]
        direction LR
        Eye["<b>Subject Visual Field</b><br/>Diffuse retinal illumination"]
        Gaze["<b>Eye-Tracking Cameras</b><br/>Unobstructed pupil tracking"]
    end

    LEDAssembly --> Eye
    NeonFrame -.-> Gaze
```

1. **Boom Arm Attachment:** The boom arm securely clips/fastens to the Neon eye-tracker frame without altering gaze-calibration geometry.
2. **Diffuser & LED Insertion:** The miniature LED assembly seats directly into the diffuser housing (`diffuser_fullipt.ipt`), placing an evenly diffused light source in the peripheral or full visual field.
3. **Cable Routing:** Lightweight, flexible silicone wiring runs along the glasses temple to prevent torque or movement artifacts during natural head motion and walking tasks.

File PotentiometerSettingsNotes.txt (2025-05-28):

vdark = 11.7mV

green ~ 436 on pot for 7.2., 408 (just) for 0.72
UV ~ 449 for 9.1, 421 for 0.91

get charger

pot levels for 10^2

gamma correction 2 colours x 2 luminance

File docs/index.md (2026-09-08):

# Full-Field LED Visual Stimulator

An open-source, high-precision visual stimulation platform designed for visual neuroscience, sensory physiology, and human psychophysics. The system delivers temporally agile, multi-chromatic optical stimulation (e.g., Green for M-cones/rods and UV for S-cones, or custom multi-spectral arrays) with sub-millisecond precision.

---

## Key Capabilities

- **High-Resolution Temporal Modulation:** 31.25 kHz Phase-Correct carrier PWM combined with a 32-bit Direct Digital Synthesis (DDS) engine eliminates saccadic Critical Flicker Fusion (CFF) artifacts, photodiode ringing, and software loop jitter.
- **Rich Stimulus Battery:** Dual-frequency sinusoidal flicker, raised cosine temporal onset/offset envelopes, dynamic contrast envelopes, continuous chirps, stepped frequency sweeps, Gaussian white noise (with Central Limit Theorem PRNG), and contrast-switching adaptation sequences.
- **Quantitative Radiometric Calibration:** End-to-end MATLAB calibration pipeline mapping raw duty cycles to linearized lookup tables (LUTs) and calculating exact photoreceptor isomerisation rates ($R^*/\text{photoreceptor/s}$).
- **Flexible Form Factors:** Supports both 200mm full-field panel enclosures (with magnetic diffusion clamping) and miniature wearable mounts for Pupil Labs Neon eye-tracking glasses.
- **Reactive Experiment Orchestration:** Full integration with [Bonsai](https://bonsai-rx.org/) for closed-loop, state-dependent, and adaptive psychometric staircase stimulation.

---

## System Architecture

```mermaid
flowchart LR
    Host["<b>Host Control (PC)</b><br/>• Bonsai Workflows<br/>• MATLAB Calibration<br/>• Serial ASCII Protocol"]
    MCU["<b>Microcontroller Engine</b><br/>• 32-bit DDS Waveforms<br/>• Flash Gamma LUT<br/>• 31.25 kHz Timer1 PWM"]
    HW["<b>Driver and LEDs</b><br/>• Driver Board and Bias<br/>• Dual LED Arrays<br/>• TTL Sync Pins 4 and 5"]
    Optics["<b>Optics and Delivery</b><br/>• Diffusion Enclosure<br/>• Wearable Frame<br/>• Homogeneous Field"]

    Host -->|Serial ASCII 115200| MCU
    MCU -->|PWM Carrier| HW
    HW -->|Linear Photons| Optics
```

---

## Quickstart Guide

### 1. Flash the Firmware
1. Open `ArduinoCode/StimulusControlViaSerial_Leonardo_DDS_8bit_2freq/StimulusControlViaSerial_Leonardo_DDS_8bit_2freq.ino` in the Arduino IDE.
2. Select **Arduino Leonardo** as your board and choose the corresponding COM port.
3. Click **Upload**.

### 2. Connect Hardware & Verify
1. Connect your LED driver to the designated MCU pins (PWM: Pins 9 & 10; Indicators: Pins 4 & 5).
2. Open the Serial Monitor at `115200` baud.
3. Send a test sinusoidal flicker:
   ```text
   s, 3000, 4.0, 4.0, 0.0, 0.5, 0.8, 0.8
   ```
   *(Runs a 3-second, 4 Hz antiphase flicker on Channels A and B at 80% contrast).*

### 3. Launch Experimental Workflows
Open [Bonsai](https://bonsai-rx.org/) and load one of the pre-built visual stimulation workflows from `BonsaiCode/` (e.g., `LEDstimulation_normal.bonsai` or `ManualMethodOfAdjustment.bonsai`).

---

## Navigation & Sections

Use the left sidebar to navigate between documentation sections:

- **[1. Hardware](1-hardware/circuit-and-driver.md)**: Schematics, custom PCBs, CAD enclosures, and Bill of Materials.
- **[2. Firmware](2-firmware/architecture-and-timers.md)**: Hardware timer registers, DDS engines, and full Serial API command reference.
- **[3. Calibration](3-calibration/calibration-guide.md)**: Radiometric power measurement, MATLAB gamma LUT pipeline, and photoreceptor opsin calculations.
- **[4. Experimental Workflows](4-experimental-workflows/bonsai-overview.md)**: Bonsai visual workflows, animal/human paradigms, Pupil Labs Neon integration, and LSL synchronization.
- **[5. Reference](5-reference/performance-and-sync.md)**: Switching dynamics, dead zones, thermal stability, and hardware trigger sync.

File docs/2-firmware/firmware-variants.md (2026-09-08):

# Firmware Variants & Selection Guide

The repository includes several firmware variants developed for different microcontrollers, experimental paradigms, and rig configurations.

---

## Firmware Variant Matrix

| Sketch Directory | Target MCU | Core Engine | Key Features | Status |
| :--- | :--- | :--- | :--- | :--- |
| **[`StimulusControlViaSerial_Leonardo_DDS_8bit_2freq`](file:///d:/Code/LEDStimulation/ArduinoCode/StimulusControlViaSerial_Leonardo_DDS_8bit_2freq/)** | Arduino Leonardo (ATmega32U4) | Direct Digital Synthesis (DDS) @ 31.25 kHz | Dual independent channel frequencies (`freqA`, `freqB`), raised cosine onset/offset envelopes, contrast envelope modulation (`se`), continuous/stepped sweeps | **Canonical / Primary** |
| **[`StimulusControlViaSerial_Leonardo_v8`](file:///d:/Code/LEDStimulation/ArduinoCode/StimulusControlViaSerial_Leonardo_v8/)** | Arduino Leonardo (ATmega32U4) | Dual Timer (Timer1 PWM + Timer3 CTC ISR) | Stochastic stimuli suite: Gaussian white noise (`wn`), frozen noise (`fwn`), contrast-switching adaptation noise (`cs`) | **Specialized / Extra Stimuli** |
| **[`StimulusControlViaSerial_Leonardo_DDS_8bit_mouseRig`](file:///d:/Code/LEDStimulation/ArduinoCode/StimulusControlViaSerial_Leonardo_DDS_8bit_mouseRig/)** | Arduino Leonardo (ATmega32U4) | Direct Digital Synthesis (DDS) @ 31.25 kHz | Single-frequency DDS variant configured with calibrated gamma LUTs for the mouse physiology rig | **Active / Rig-Specific** |
| **[`LEDStimController_Teensy41_DDS`](file:///d:/Code/LEDStimulation/ArduinoCode/LEDStimController_Teensy41_DDS/)** | Teensy 4.1 (ARM Cortex-M7 @ 600MHz) | FlexPWM (12-bit @ 36.6 kHz) + IntervalTimer DDS | 4096-entry sine table, runtime gamma LUT streaming (`loadlut`), post-LUT brightness scaling (`bright`) | **High-Performance Alternative** |
| **[`IMUscript_Task`](file:///d:/Code/LEDStimulation/ArduinoCode/IMUscript_Task/)** | Arduino Leonardo / Compatible | Serial IMU Data Acquisition | Real-time 6-DOF IMU streaming for movement and gait synchronization in human psychophysics | **Auxiliary / Motion Tracking** |

---

## 1. Canonical Firmware: `StimulusControlViaSerial_Leonardo_DDS_8bit_2freq`

This is the **primary, recommended firmware** for general visual stimulation experiments.

* **Target Hardware:** Arduino Leonardo (ATmega32U4 @ 16 MHz).
* **PWM Carrier:** 31.25 kHz (Timer1 Phase Correct PWM, Mode 10, TOP = 256).
* **Waveform Synthesis:** 32-bit Direct Digital Synthesis (DDS) phase accumulator updated synchronously on every PWM cycle via `TIMER1_OVF_vect`.
* **Key Capabilities:**
    * **Dual-Frequency Control:** Channel A and Channel B can run at distinct temporal frequencies (`freqA`, `freqB`), phases, and contrasts.
    * **Smooth Envelopes:** 100 ms modular raised cosine window (`raisedCosineLUT[64]`) prevents startle transients on trial onset and offset.
    * **Contrast Modulation (`se`):** Sinusoidal flicker modulated by a dynamic sinusoidal contrast envelope.
    * **Continuous (`fs`) & Stepped (`sfs`) Sweeps:** Frequency chirps and discrete cycle-counted frequency staircases.
    * **USB SOF Suppression:** Disables Timer0 and USB Start-of-Frame interrupts during stimulation to eliminate trial timing drift.

---

## 2. Stochastic & Discrete Stimuli: `StimulusControlViaSerial_Leonardo_v8`

This sketch contains additional stochastic and discrete noise stimulus patterns that are not present in the DDS version:

* **Target Hardware:** Arduino Leonardo (ATmega32U4 @ 16 MHz).
* **Architecture:** Uses a dual-timer scheme where `Timer1` generates the carrier PWM and `Timer3` fires discrete CTC interrupts (`TIMER3_COMPA_vect`) at the frame update rate (e.g., 100 Hz).
* **Additional Stimuli Provided:**
    * **Gaussian White Noise (`wn`):** Real-time Gaussian pseudo-random luminance frames using `xorshift32` + Central Limit Theorem ($N=10$).
    * **Frozen White Noise (`fwn`):** Deterministic, repeatable pseudo-random sequence with a defined PRNG seed for trial-averaging.
    * **Contrast-Switching White Noise (`cs`):** 2-state adaptation noise alternating between two contrast and mean states.
    * **16-bit PWM Resolution:** Configurable dynamic prescaler/TOP up to 16 bits.

---

## 3. Mouse Rig Firmware: `StimulusControlViaSerial_Leonardo_DDS_8bit_mouseRig`

* **Target Hardware:** Arduino Leonardo (ATmega32U4 @ 16 MHz).
* **Architecture:** Direct Digital Synthesis (DDS) identical to the canonical engine, with pre-configured empirical gamma calibration tables embedded directly in `PROGMEM` for the mouse experimental rig.

---

## 4. 32-bit ARM Alternative: `LEDStimController_Teensy41_DDS`

* **Target Hardware:** PJRC Teensy 4.1 (600 MHz ARM Cortex-M7).
* **Architecture:** Hardware `FlexPWM` running at **36.62 kHz** (12-bit resolution, 4096 steps) with 32-bit DDS driven by an `IntervalTimer` (PIT).
* **Key Capabilities:**
    * **12-bit Dynamic Range:** 4096 discrete luminance levels per channel.
    * **Serial LUT Streaming (`loadlut`):** Allows uploading empirical gamma calibration curves dynamically over USB without re-flashing firmware.
    * **Dynamic Brightness Scaling (`bright`):** Post-LUT master attenuation ($0-100\%$) for rapid adaptation without rebuilding LUTs.

---

## 5. Auxiliary Tracking: `IMUscript_Task`

* **Target Hardware:** Arduino Leonardo or compatible board with an I2C/SPI IMU sensor (e.g., MPU-6050 / BNO055).
* **Purpose:** Streams 6-DOF acceleration and angular velocity over serial to synchronize visual stimulation with subject movement or head kinematics in human experiments.

---

## Paradigm Selection Guide

```mermaid
flowchart TD
    Start{"<b>What stimulus paradigm is required?</b>"}
    
    Start -->|"Sinewaves, Chirps, Contrast Envelopes"| Canonical["<b>Canonical DDS Firmware</b><br/><code>DDS_8bit_2freq.ino</code>"]
    Start -->|"Gaussian Noise, Frozen Noise, Adaptation"| v8["<b>Stochastic Noise Suite</b><br/><code>Leonardo_v8.ino</code>"]
    Start -->|"12-bit Resolution / Dynamic LUT Upload"| Teensy["<b>High-Resolution ARM Cortex-M7</b><br/><code>Teensy41_DDS.ino</code>"]
    Start -->|"Head Kinematics & Motion Capture"| IMU["<b>Motion Telemetry</b><br/><code>IMUscript_Task.ino</code>"]
```

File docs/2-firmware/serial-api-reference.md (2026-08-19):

# Serial API Reference

The visual stimulator communicates with host software (e.g., Bonsai, MATLAB, Python) via USB Serial using comma-separated ASCII commands.

* **Baud Rate:** `115200`
* **Data Format:** `8` Data Bits | `No` Parity | `1` Stop Bit
* **Line Termination:** Carriage Return (`\r`) or Newline (`\n`)
* **Completion Handshake:** After executing any timed stimulus command, the firmware returns `-1\n` over Serial to notify the host that the presentation is finished.

---

## Command Quick Reference

| Command Type | Key | Syntax | Primary Firmware | Description |
| :--- | :--- | :--- | :--- | :--- |
| **Dual-Frequency Sinewave** | `s` | `s, Duration, FreqA, FreqB, PhaseA, PhaseB, ContrastA, ContrastB` | `DDS_8bit_2freq` *(Canonical)* | Dual-channel sine flicker with independent frequencies & raised cosine window |
| **Contrast Envelope Sine** | `se` | `se, Duration, FreqA, FreqB, EnvFreq, MaxContrastA, MaxContrastB` | `DDS_8bit_2freq` *(Canonical)* | Sinusoidal flicker modulated by a sinusoidal contrast envelope |
| **Stepped Frequency Sweep** | `sfs` | `sfs, StartFreq, EndFreq, StepFreq, CyclesPerFreq, PhaseA, PhaseB, ContrastA, ContrastB` | `DDS_8bit_2freq` *(Canonical)* | Frequency sweep holding exact integer cycles per frequency step |
| **Continuous Chirp Sweep** | `fs` | `fs, Fmin, Fmax, SweepFactor, PhaseA, PhaseB, ContrastA, ContrastB` | `DDS_8bit_2freq` & `v8` | Exponential continuous frequency sweep from $F_{\text{min}} \to F_{\text{max}} \to F_{\text{min}}$ |
| **Timed DC Step** | `sdt` | `sdt, DutyA, DutyB, Duration` | `DDS_8bit_2freq` & `v8` | Fixed DC luminance step for a defined duration |
| **Static DC Output** | `sd` | `sd, DutyA, DutyB` | All Variants | Continuous static DC output ($0-100\%$) |
| **Gaussian White Noise** | `wn` | `wn, Duration, UpdateTime, MeanFrac, StdFrac` | `Leonardo_v8` *(Stochastic)* | Continuous pseudo-random Gaussian luminance noise |
| **Frozen White Noise** | `fwn` | `fwn, Duration, UpdateTime, Reps, Seed` | `Leonardo_v8` *(Stochastic)* | Deterministic, repeatable pseudo-random Gaussian sequence |
| **Switching Noise** | `cs` | `cs, UpdateTime, SwitchTime, Reps, Mean1, Cont1, Mean2, Cont2` | `Leonardo_v8` *(Stochastic)* | 2-state adaptation noise alternating contrast/mean distributions |
| **Gamma Calibration** | `gc` | `gc, Step, Wait, Reps` | All Variants | Step-wise luminance staircase for photodiode/power meter calibration |
| **Select LUT Bank** | `agc` | `agc, Index` | All Variants | Switch active gamma LUT bank (`1` = Linear, `2` = Calibrated) |
| **Channel Enable** | `useChA` / `useChB` | `useChA, 1/0` / `useChB, 1/0` | All Variants | Enable (`1`) or mute (`0`) LED channel output |
| **Analog Stream** | `ana` | `ana` | All Variants | Stream live potentiometer readings from A0/A1 (`done` to stop) |
| **Brightness Scale** | `bright` | `bright, Channel, Percent` | `Teensy41_DDS` | Dynamic master attenuation without rebuilding LUT |
| **Upload Gamma LUT** | `loadlut` | `loadlut, Channel, v0, v1, ...` | `Teensy41_DDS` | Upload 4096-point empirical LUT over serial at runtime |

---

## Detailed Command Specifications

### 1. Dual-Frequency Sinusoidal Flicker (`s`)

Generates single- or dual-channel sinusoidal flicker with independent frequency, phase, and contrast modulation on each channel. Includes a 100 ms raised cosine fade-in/fade-out window.

```text
s, Duration, FreqA, FreqB, PhaseA, PhaseB, ContrastA, ContrastB
```

* **`Duration`** *(long, ms)*: Total duration of the stimulus in milliseconds.
* **`FreqA` / `FreqB`** *(float, Hz)*: Temporal modulation frequency in Hertz for Channel A and Channel B (e.g. `2.0`, `10.5`).
* **`PhaseA` / `PhaseB`** *(float, 0.0 – 1.0)*: Relative starting phase offset ($1.0 = 2\pi\text{ rad} = 360^\circ$). For antiphase stimulation ($180^\circ$), set Channel A to `0.0` and Channel B to `0.5`.
* **`ContrastA` / `ContrastB`** *(float, 0.0 – 1.0)*: Michelson contrast / modulation depth ($0.0 = 0\%$, $1.0 = 100\%$).
* **Example:** `s, 5000, 4.0, 4.0, 0.0, 0.5, 0.8, 0.8` *(5-second 4 Hz antiphase flicker at 80% contrast)*.
* **Dual-Frequency Example:** `s, 10000, 5.0, 7.5, 0.0, 0.0, 1.0, 1.0` *(10-second dichoptic flicker: 5 Hz on Ch A, 7.5 Hz on Ch B)*.

---

### 2. Sinusoidal Flicker with Contrast Envelope (`se`)

Modulates high-frequency sinusoidal flicker with a secondary low-frequency sinusoidal contrast envelope. The envelope starts at absolute trough ($270^\circ = 0\text{ contrast}$) and smoothly increases to peak contrast and back.

```text
se, Duration, FreqA, FreqB, EnvFreq, MaxContrastA, MaxContrastB
```

* **`Duration`** *(long, ms)*: Total stimulus duration in milliseconds.
* **`FreqA` / `FreqB`** *(float, Hz)*: Carrier frequency in Hertz for Channel A and Channel B.
* **`EnvFreq`** *(float, Hz)*: Modulation frequency of the contrast envelope (e.g. `0.2` Hz for a 5-second envelope cycle).
* **`MaxContrastA` / `MaxContrastB`** *(float, 0.0 – 1.0)*: Peak modulation contrast reached at envelope maximum.
* **Example:** `se, 10000, 10.0, 10.0, 0.5, 0.9, 0.9` *(10-second 10 Hz flicker enveloped by a 0.5 Hz contrast cycle at 90% peak contrast)*.

---

### 3. Stepped Frequency Sweep (`sfs`)

Sweeps through a series of discrete frequencies from `StartFreq` to `EndFreq` in steps of `StepFreq`, holding each frequency for an exact integer number of full sine wave cycles (`CyclesPerFreq`).

```text
sfs, StartFreq, EndFreq, StepFreq, CyclesPerFreq, PhaseA, PhaseB, ContrastA, ContrastB
```

* **`StartFreq` / `EndFreq`** *(float, Hz)*: Initial and final frequencies in Hertz. If `StartFreq < EndFreq`, sweeps upward; if `StartFreq > EndFreq`, sweeps downward.
* **`StepFreq`** *(float, Hz)*: Frequency increment per step (automatically forced positive).
* **`CyclesPerFreq`** *(int)*: Number of complete sine cycles presented at each frequency step.
* **`PhaseA` / `PhaseB`** *(float, 0.0 – 1.0)*: Initial phase offsets.
* **`ContrastA` / `ContrastB`** *(float, 0.0 – 1.0)*: Modulation contrast depth.
* **Example:** `sfs, 1.0, 20.0, 1.0, 5, 0.0, 0.0, 0.8, 0.8` *(Sweeps from 1 Hz to 20 Hz in 1 Hz steps, presenting exactly 5 full cycles per step)*.

!!! tip "Stepped Sweep Duration Calculation"
    The exact total presentation duration for `sfs` can be calculated in MATLAB using [`calculateSteppedSweepDuration.m`](file:///d:/Code/LEDStimulation/ArduinoCode/calculateSteppedSweepDuration.m).

---

### 4. Continuous Exponential Frequency Chirp (`fs`)

Generates a continuous exponential frequency chirp starting at $F_{\text{min}}$, accelerating up to $F_{\text{max}}$, and smoothly returning to $F_{\text{min}}$.

```text
fs, Fmin, Fmax, SweepFactor, PhaseA, PhaseB, ContrastA, ContrastB
```

* **`Fmin` / `Fmax`** *(float, Hz)*: Minimum and maximum frequencies of the chirp sweep.
* **`SweepFactor`** *(float)*: Exponential rate factor $M$ from $f(t) = f_0 \exp(Mt)$.
* **`PhaseA` / `PhaseB`** *(float, 0.0 – 1.0)*: Initial phase offsets.
* **`ContrastA` / `ContrastB`** *(float, 0.0 – 1.0)*: Modulation contrast depths.
* **Example:** `fs, 1.0, 30.0, 0.5, 0.0, 0.0, 0.75, 0.75` *(Continuous logarithmic chirp between 1 Hz and 30 Hz)*.

---

### 5. Gaussian White Noise (`wn`) — *Leonardo v8 Firmware*

Generates continuous pseudo-random luminance frames drawn from a Gaussian distribution at a fixed frame rate.

```text
wn, Duration, UpdateTime, MeanFrac, StdFrac
```

* **`Duration`** *(long, ms)*: Total presentation duration in milliseconds.
* **`UpdateTime`** *(long, ms)*: Duration of each discrete frame in milliseconds (e.g. `10` ms for 100 Hz frame rate).
* **`MeanFrac`** *(float, 0.0 – 1.0)*: Mean baseline luminance level ($0.5 = 50\%$ duty cycle).
* **`StdFrac`** *(float, 0.0 – 1.0)*: Standard deviation of the Gaussian distribution (sets noise contrast).
* **Example:** `wn, 10000, 10, 0.5, 0.15` *(10-second Gaussian noise, 100 Hz refresh rate, 50% mean luminance, 15% standard deviation)*.

---

### 6. Frozen White Noise (`fwn`) — *Leonardo v8 Firmware*

Pre-computes a deterministic Gaussian noise sequence into a local buffer and repeats it identically across blocks to permit trial-averaged neural response analysis.

```text
fwn, Duration, UpdateTime, Reps, Seed
```

* **`Duration`** *(long, ms)*: Duration of a single frozen sequence in milliseconds.
* **`UpdateTime`** *(int, ms)*: Frame interval in milliseconds.
* **`Reps`** *(int)*: Number of times to loop the exact sequence.
* **`Seed`** *(int)*: PRNG seed integer to ensure identical random sequences across days/rigs.
* **Example:** `fwn, 2000, 10, 5, 42` *(Repeats identical 2-second Gaussian sequence 5 times using seed 42)*.

---

### 7. Contrast-Switching Adaptation Noise (`cs`) — *Leonardo v8 Firmware*

Periodically alternates between two distinct Gaussian distributions to probe dynamic sensory gain control and neural contrast adaptation kinetics.

```text
cs, UpdateTime, SwitchTime, Reps, Mean1, Cont1, Mean2, Cont2
```

* **`UpdateTime`** *(int, ms)*: Noise frame interval in milliseconds.
* **`SwitchTime`** *(int, ms)*: Duration in milliseconds before toggling to the alternative distribution.
* **`Reps`** *(int)*: Total number of distribution switch cycles.
* **`Mean1`, `Cont1`**: Mean ($0.0-1.0$) and Contrast/Std for State 1.
* **`Mean2`, `Cont2`**: Mean ($0.0-1.0$) and Contrast/Std for State 2.
* **Example:** `cs, 10, 3000, 10, 0.5, 0.05, 0.5, 0.25` *(Alternates every 3 seconds between 5% and 25% contrast for 10 cycles)*.

---

### 8. Timed Luminance Step (`sdt`)

Applies a static DC duty cycle for a specified duration before resetting to baseline.

```text
sdt, DutyA, DutyB, Duration
```

* **`DutyA` / `DutyB`** *(float, 0.0 – 100.0)*: Output duty cycle percentage for Channel A and Channel B.
* **`Duration`** *(long, ms)*: Step hold duration in milliseconds.
* **Example:** `sdt, 75.0, 0.0, 1000` *(1-second 75% luminance pulse on Channel A)*.

---

### 9. Static Output (`sd`)

Sets continuous DC duty cycle without automatic timeout.

```text
sd, DutyA, DutyB
```

* **`DutyA` / `DutyB`** *(float, 0.0 – 100.0)*: Output duty cycle percentage.
* **Example:** `sd, 0, 0` *(Turns off both LED channels)*.

---

### 10. Calibration & Utility Commands

#### Gamma Calibration Staircase (`gc`)

```text
gc, Step, Wait, Reps
```

Iterates through luminance levels from $0\%$ to $100\%$ in increments of `Step` percent, holding each level for `Wait` milliseconds, repeated `Reps` times. Used during optical power meter or photodiode calibration sweeps.

#### Active Gamma LUT Selection (`agc`)

```text
agc, Index
```

Switches active gamma correction LUT bank (`1` = Bank 1 / Linear, `2` = Bank 2 / Calibrated empirical LUT).

#### Channel Enable / Mute (`useChA` / `useChB`)

```text
useChA, 1
useChB, 0
```

Enables (`1`) or mutes (`0`) the selected output channel.

#### Analog Stream (`ana`)

```text
ana
```

Streams continuous analog sensor values from pins A0 and A1 over Serial at 100 ms intervals to monitor manual potentiometer adjustments. Send `done\n` to terminate streaming.

---

## 11. Teensy 4.1 Extensions

When running the [`LEDStimController_Teensy41_DDS.ino`](file:///d:/Code/LEDStimulation/ArduinoCode/LEDStimController_Teensy41_DDS/LEDStimController_Teensy41_DDS.ino) firmware, the following additional commands are supported:

### Master Brightness Scaling (`bright`)

```text
bright, Channel, Percent
```

Applies post-LUT master digital attenuation ($0-100\%$) to Channel `A` or `B` without needing to re-generate or re-upload gamma tables.

* **Example:** `bright, A, 50` *(Scales Channel A maximum brightness to 50%)*.

### Runtime Gamma LUT Upload (`loadlut`)

```text
loadlut, Channel, v0, v1, v2, ...
```

Uploads a 4096-entry 12-bit calibration curve directly over serial into RAM for immediate runtime linearization.

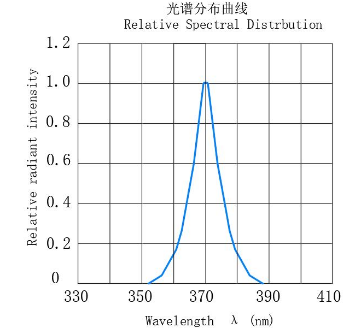
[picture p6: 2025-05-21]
Calibration/LEDdata/UV_spectralDistribution.png

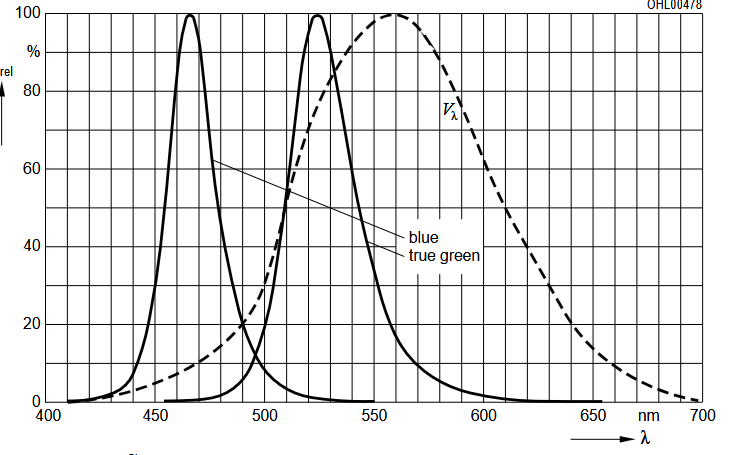
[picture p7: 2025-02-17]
Calibration/green_LED_spectrum_image.png

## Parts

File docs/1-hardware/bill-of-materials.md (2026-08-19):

# Bill of Materials (BOM)

This Bill of Materials is categorized by subsystem. Sourcing links, specific part numbers, and references are provided below.

---

## 1. Full-Field Panel Enclosure & Mechanics

| Category | Part Description | Source / Reference | Quantity | Notes |
| :--- | :--- | :--- | :--- | :--- |
| **Chassis** | MakerBeam XL 200mm (Black Anodized) | [Technobots Online](https://www.technobotsonline.com/makerbeamxl-200mm-long-black-anodised-beam-threaded.html) | 8 | Main cube frame |
| **Chassis** | MakerBeam XL 50mm (Black Anodized) | [Technobots Online](https://www.technobotsonline.com/makerbeamxl-50mm-long-black-anodised-beam-threaded.html) | 4 | Vertical riser beams |
| **Chassis** | MakerBeam XL Corner Cubes (Pack of 12) | [Technobots Online](https://www.technobotsonline.com/makerbeam-xl-black-corner-cubes-pack-of-12.html) | 8 cubes | Corner joints |
| **Fasteners** | M3 Button Head Socket Screws (6mm / 10mm) | [Technobots Online](https://www.technobotsonline.com/button-head-socket-cap-stainless-screw-m3x6mm-pk-100.html) | ~200 | Frame assembly & baseplate mounting |
| **Fasteners** | MakerBeam XL M3 T-Slot / Square Nuts | [Technobots Online](https://www.technobotsonline.com/) | 50+ | Slides into 15x15mm extrusion slots |
| **Baseplate** | Custom Aluminium Baseplate | [`Hardware/Enclosure/Baseplate_for_PCBs_v3.stp`](file:///d:/Code/LEDStimulation/Hardware/Enclosure/Baseplate_for_PCBs_v3.stp) | 1 | CNC milled / laser cut aluminium heatsink plate |
| **Diffusion Base** | Corner Diffusion Base (Screws + Magnets) | [`Hardware/Enclosure/box_corner_screws_and_magnets.stl`](file:///d:/Code/LEDStimulation/Hardware/Enclosure/box_corner_screws_and_magnets.stl) | 4 | 3D printed |
| **Diffusion Base** | Edge Diffusion Base (Screws + Magnets) | [`Hardware/Enclosure/box_long_edge_screws_and_magnets.stl`](file:///d:/Code/LEDStimulation/Hardware/Enclosure/box_long_edge_screws_and_magnets.stl) | 4 | 3D printed |
| **Diffusion Clamp** | Corner Diffusion Magnetic Clamp | [`Hardware/Enclosure/box_corner_just_magnets.stl`](file:///d:/Code/LEDStimulation/Hardware/Enclosure/box_corner_just_magnets.stl) | 4 | 3D printed |
| **Diffusion Clamp** | Edge Diffusion Magnetic Clamp | [`Hardware/Enclosure/box_long_edge_just_magnets.stl`](file:///d:/Code/LEDStimulation/Hardware/Enclosure/box_long_edge_just_magnets.stl) | 4 | 3D printed |
| **Magnets** | 5mm $\times$ 2–3mm Neodymium Disc Magnets | [Amazon UK](https://www.amazon.co.uk/Magnet-Expert%C2%AE-5mm-thick-Neodymium/dp/B00TACMMP0/) | 16 | 8 clamp positions $\times$ 2 magnets (base + clamp) |
| **Diffuser** | Tracing paper works well for diffusing and passing through the UV / visible light spectrum. Larger panels may benefit from multiple sheets. | 1 | Sized to 200 $\times$ 200 mm |
| **3D Print Set** | Complete Enclosure 3D Print Package | [`Hardware/Enclosure/UM3_all3dprintedparts.3mf`](file:///d:/Code/LEDStimulation/Hardware/Enclosure/UM3_all3dprintedparts.3mf) | 1 set | Combined Ultimaker / Bambu 3MF package |

---

## 2. Optoelectronics & LED Boards

| Category | Part Description | Source / Reference | Quantity | Notes |
| :--- | :--- | :--- | :--- | :--- |
| **Green LEDs** | Xinglight XL-2835UGC-02 (525nm peak, SMD 2835) | [LCSC (C2843870)](https://www.lcsc.com/product-detail/Light-Emitting-Diodes-LED_XINGLIGHT-XL-2835UGC-02_C2843870.html) | 6 per board | M-cone / Rod stimulation (2 series banks of 3) |
| **UV LEDs** | Xinglight XL-2835UVA-02 (395–405nm peak, SMD 2835) | [LCSC (C2843877)](https://www.lcsc.com/product-detail/Light-Emitting-Diodes-LED_XINGLIGHT-XL-2835UVA-02_C2843877.html) | 6 per board | S-cone stimulation (2 series banks of 3) |
| **PCB** | Custom Dual-Channel LED PCB | [`Hardware/LED_board/`](file:///d:/Code/LEDStimulation/Hardware/LED_board/) | 1 to 4 | Standard panel array (JLCPCB production files in `production/`) |
| **PCB (3-Colour)**| 3-Colour LED PCB (`LED_board_humans`) | [`Hardware/LED_board_humans/`](file:///d:/Code/LEDStimulation/Hardware/LED_board_humans/) | – | *WIP* – Experimental 3-colour panel PCB |
| **Connectors** | 2-pin 2.54mm Right-Angled Female Sockets & Male Headers | Standard supplier | 4 per board | `PinSocket_1x02_P2.54mm_Horizontal` for LED bank wiring |
| **Hardware** | M3 Nylon Spacers (2mm) | Standard supplier | 4–16 | PCB standoff thermal and electrical isolation |
| **Hardware** | M3 $\times$ 10mm Flanged Button Screws & Nuts | [Accu](https://www.accu.co.uk/flanged-button-screws/8595-SSBF-M3-10-A2) | 4–16 | PCB mounting to baseplate |

---

## 3. Control & Driver Electronics

| Category | Part Description | Source / Reference | Quantity | Notes |
| :--- | :--- | :--- | :--- | :--- |
| **Microcontroller** | Arduino Leonardo (ATmega32u4, 5V / 16MHz) | Arduino Official / Authorized Distributor | 1 | Default controller (Timer 1/3 high-speed PWM) |
| **Microcontroller** | Teensy 4.1 (ARM Cortex-M7, 600MHz) *(Optional)* | PJRC / SparkFun | 1 | High-speed DDS variant |
| **Transistor Switch** | NPN Bipolar Junction Transistor (e.g. onsemi 2N3904, TO-92) | Standard supplier (Mouser / Farnell / Digikey) | 1 per channel | Low-side switch ($40\,\text{V}$, $200\,\text{mA}$ max) |
| **Potentiometers** | Multi-Turn Cermet Trimpot (e.g. 500 $\Omega$ – 10 k$\Omega$, Bourns 3296W) | Standard supplier | 1 per channel | Master peak current / luminance control (cermet is critical for PWM stability) |
| **Fixed Resistors** | $R_{\text{fixed}}$ Series Current-Limiting Resistors (51 $\Omega$ – 330 $\Omega$, 1/4W) | Standard supplier | 1 per LED line | Protects LEDs and sets current ceiling when trimpot is at $0\,\Omega$ |
| **Base Resistors** | $R_{\text{base}}$ Base Resistors (100 $\Omega$, 1/4W) | Standard supplier | 1 per channel | Limits base switching current from Arduino pin |
| **Pull-down Resistors** | $R_{\text{pull-down}}$ Pull-Down Resistors (10 k$\Omega$, 1/4W) | Standard supplier | 1 per channel | Keeps transistor OFF during boot / floating GPIO |
| **Power Supply** | $+12\,\text{V}$ DC Power Supply (1A–2A, Regulated) | Standard supplier | 1 | External power rail for multi-LED series strings |
| **Prototyping** | Solderless Breadboard or Stripboard / Perfboard | Standard supplier | 1 | Benchtop circuit assembly |
| **Wiring** | USB-A to Micro-USB Cable & Jumper Wires | Standard supplier | As needed | Serial communication, power & interconnections |

---

## 4. Wearable & Human Experiment Accessories

| Category | Part Description | Source / Reference | Quantity | Notes |
| :--- | :--- | :--- | :--- | :--- |
| **Eye Tracker** | Pupil Labs Neon Eye Tracker | [Pupil Labs](https://pupil-labs.com/products/neon/) | 1 | High-speed mobile gaze tracking system |
| **Mounting** | 3D Printed Glasses Boom Arm | [`Hardware/glasses/boom_arm.stl`](file:///d:/Code/LEDStimulation/Hardware/glasses/boom_arm.stl) | 1 | Custom clip mounting to Neon frame |
| **Diffuser Housing**| Miniature Glasses Diffuser Housing | [`Hardware/glasses/diffuser_fullipt.ipt`](file:///d:/Code/LEDStimulation/Hardware/glasses/diffuser_fullipt.ipt) | 1 | Positions diffuser in visual field |
| **Optics** | Miniature Stimulus LED (UV / Green) | Standard supplier / discrete LEDs | 1–2 | Inserted into glasses diffuser housing |
| **Wiring** | Ultra-flexible Silicone Hookup Wire (30 AWG) | Standard supplier | 1–2 m | Lightweight routing along glasses temple |
| **Motion Sensor** | IMU / Accelerometer *(Optional)* | Standard supplier | 1 | Body/gait synchronization |

---

## 5. Calibration Equipment

!!! important "Only ONE Calibration Setup Required"
    **Only ONE calibrated optical measurement setup is required** (Options A, B, or C below). You do **not** need all of them. Choose the option best suited to your available lab equipment and acquisition requirements.

### Option A: Standard Optical Power Meter (Recommended)
| Category | Part Description | Source / Reference | Quantity | Notes |
| :--- | :--- | :--- | :--- | :--- |
| **Power Meter** | Optical Power Meter Console (e.g. Thorlabs PM100D, PM100USB, or PM400) | [Thorlabs](https://www.thorlabs.com/) | 1 | Measures absolute optical power ($\mu\text{W}$ / $\text{nW}$) |
| **Sensor** | Calibrated UV/Visible Photodiode Sensor (e.g. Thorlabs S120VC, S121C, S130VC, or S120C) | [Thorlabs](https://www.thorlabs.com/) | 1 | Wavelength-calibrated response curve ($200\text{--}1100\,\text{nm}$) |

### Option B: High-Speed Amplified Photodiode (For Dynamic / Temporal Profiling)
| Category | Part Description | Source / Reference | Quantity | Notes |
| :--- | :--- | :--- | :--- | :--- |
| **Photodiode** | Amplified Si Photodetector (e.g. Thorlabs PDA100A2) | [Thorlabs](https://www.thorlabs.com/) | 1 | High bandwidth photodiode for fast temporal/PWM waveform verification |
| **Acquisition** | Oscilloscope or National Instruments / LabJack DAQ | Standard lab equipment | 1 | Digitizes amplified analog photodiode voltage output |

### Option C: Calibrated Spectroradiometer / Spectrometer
| Category | Part Description | Source / Reference | Quantity | Notes |
| :--- | :--- | :--- | :--- | :--- |
| **Spectrometer** | Calibrated Fiber Spectroradiometer (e.g. Ocean Optics USB2000+ / STS, Thorlabs CCS200) | Ocean Optics / Thorlabs | 1 | Directly measures full spectral irradiance distributions ($\mu\text{W/cm}^2\text{/nm}$) |

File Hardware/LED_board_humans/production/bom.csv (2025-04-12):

Designator | Footprint | Quantity | Value | LCSC Part #
D1, D10, D11, D2, D3, D9 | LED-SMD_L3.5-W2.8_RED | 6 | LED | C2843870
D13, D14, D15, D5, D6, D7 | LED-SMD_L3.5-W2.8-FD_WHITE-1 | 6 | LED | C2843877
H1, H2, H3, H4 | MountingHole_3.2mm_M3 | 4 | MountingHole
J1 | PinSocket_1x02_P2.54mm_Horizontal | 1 | Green bank 1
J2 | PinSocket_1x02_P2.54mm_Horizontal | 1 | UV bank 1
J3 | PinSocket_1x02_P2.54mm_Horizontal | 1 | Green bank 2
J4 | PinSocket_1x02_P2.54mm_Horizontal | 1 | UV bank 2

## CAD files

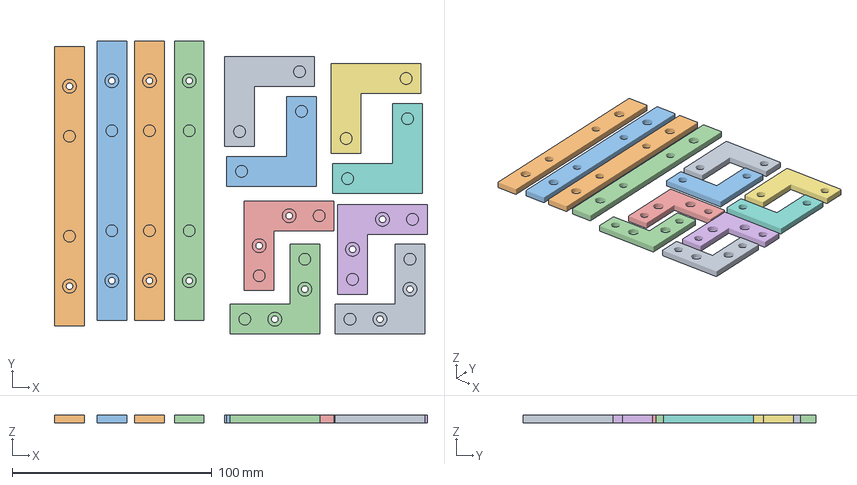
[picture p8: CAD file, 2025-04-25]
Hardware/Enclosure/UM3_all3dprintedparts.3mf
186.6 x 146.8 x 4.00 mm
box_corner_screws_and_magnets.stl
box_long_edge_screws_and_magnets.stl
box_corner_just_magnets.stl
box_corner_screws_and_magnets.stl(1)
box_corner_screws_and_magnets.stl(2)
box_corner_screws_and_magnets.stl(3)
box_corner_just_magnets.stl(1)
box_corner_just_magnets.stl(2)
box_corner_just_magnets.stl(3)
box_long_edge_screws_and_magnets.stl(1)
box_long_edge_screws_and_magnets.stl(2)
box_long_edge_screws_and_magnets.stl(3)

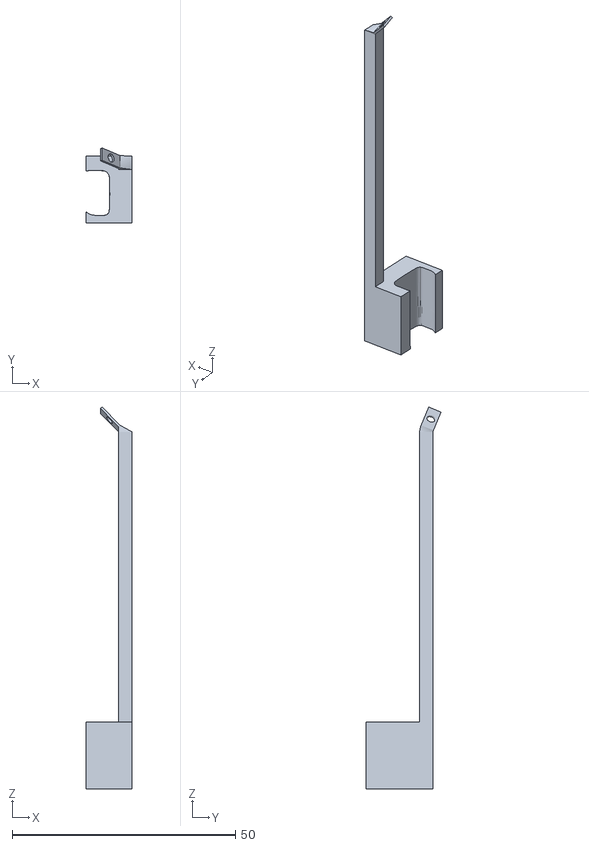
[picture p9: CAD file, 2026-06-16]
Hardware/glasses/clamp_snapon_w_arm_angles_v2.stl
10.2 x 16.8 x 85.6

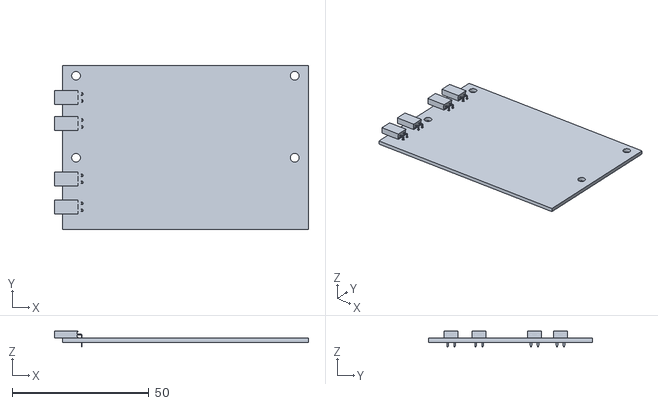
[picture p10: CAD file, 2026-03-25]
Hardware/LED_board/LED_board.stl
92.9 x 60.0 x 5.84

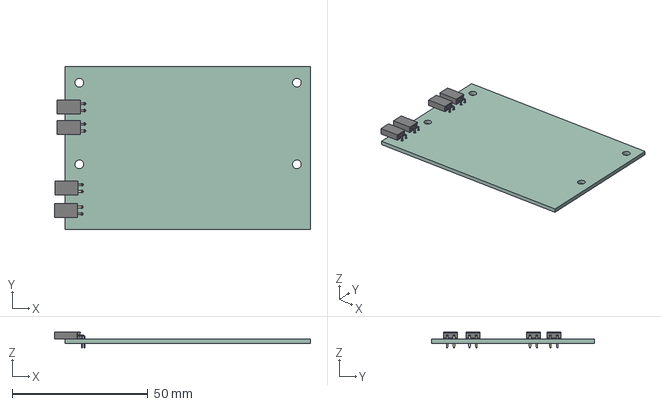
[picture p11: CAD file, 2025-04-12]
Hardware/LED_board_humans/LED_board_humans.step
94.1 x 60.0 x 5.84 mm
PinSocket_1x02_P254mm_Horizontal x 4
green_uv_led_pcb_PCB

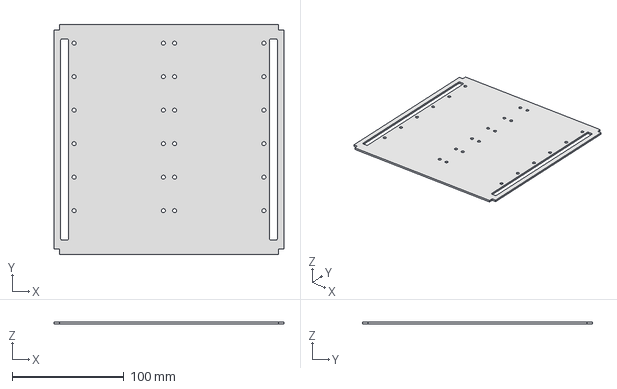
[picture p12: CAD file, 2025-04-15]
Hardware/PCB_baseplate.stp
206.0 x 206.0 x 2.00 mm

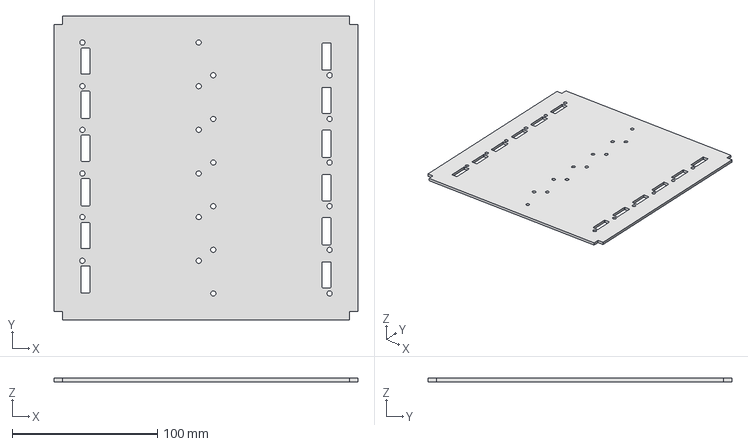
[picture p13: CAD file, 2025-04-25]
Hardware/Enclosure/Baseplate_for_PCBs_v3.stp
209.0 x 209.0 x 2.50 mm

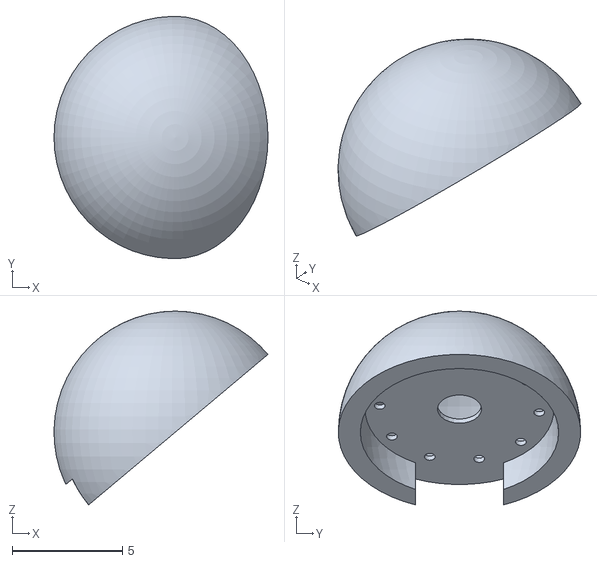
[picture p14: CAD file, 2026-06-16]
Hardware/glasses/clamp_snapon_w_arm_angles_stickOn.stl
9.71 x 11.0 x 8.80

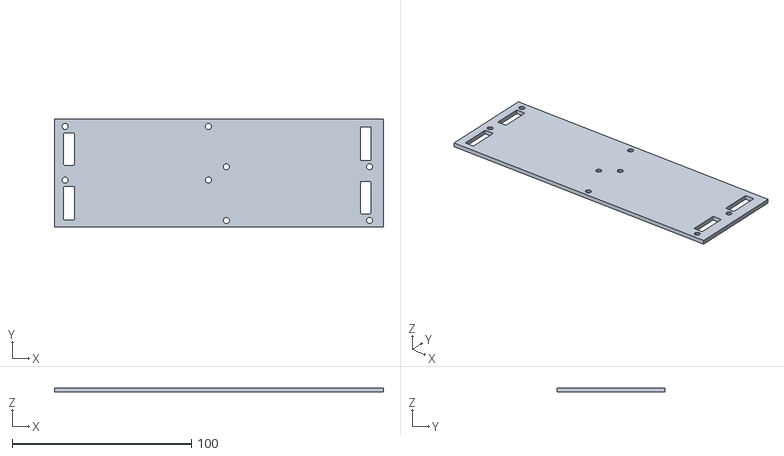
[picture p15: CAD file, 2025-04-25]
Hardware/Enclosure/Baseplate_for_PCBs_v3_section.stl
183.8 x 60.6 x 2.50

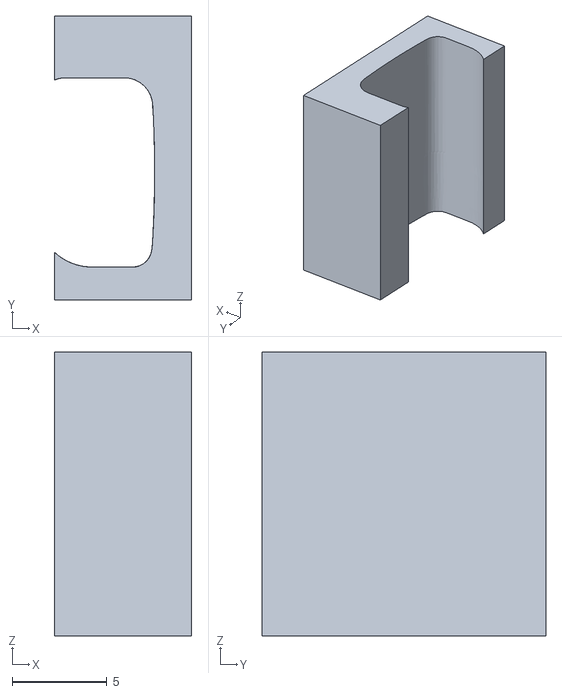
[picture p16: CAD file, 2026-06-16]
Hardware/glasses/clamp_snapon.stl
7.25 x 15.0 x 15.0

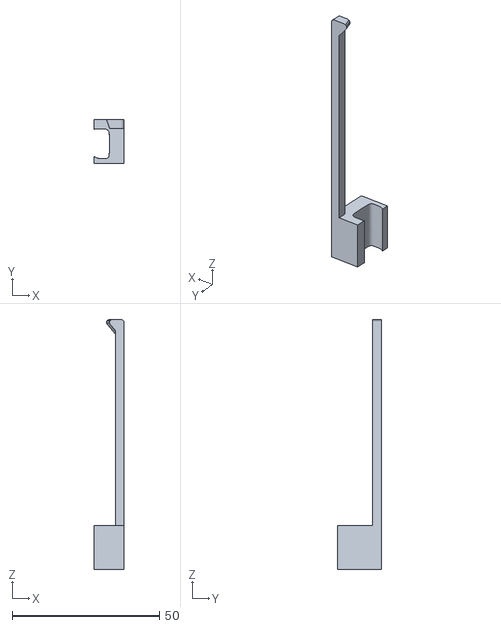
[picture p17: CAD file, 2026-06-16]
Hardware/glasses/clamp_snapon_w_arm_angles.stl
10.2 x 15.0 x 85.0

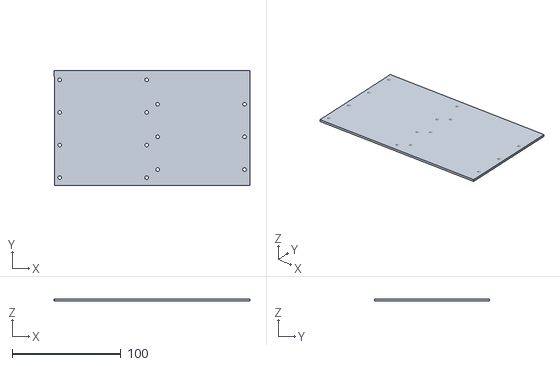
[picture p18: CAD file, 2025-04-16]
Hardware/Enclosure/Baseplate_for_PCBs_mirroredHoles_smallSectio1n.stl
180.3 x 105.6 x 2.00

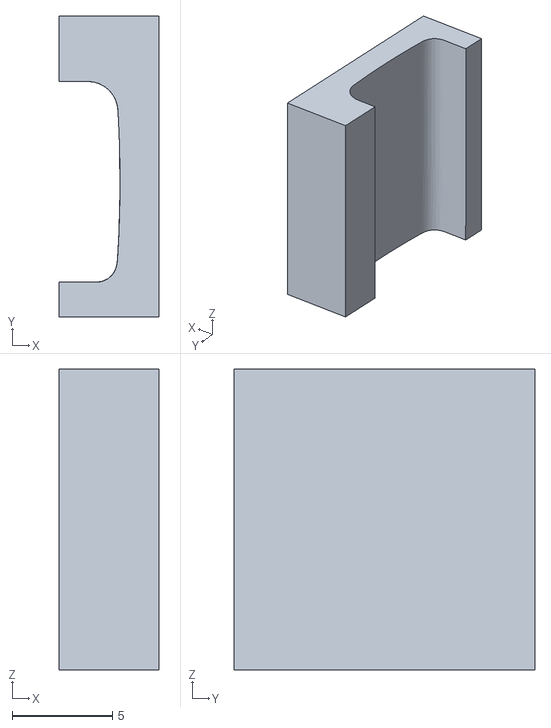
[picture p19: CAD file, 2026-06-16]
Hardware/glasses/lclamp.stl
5.00 x 15.0 x 15.0

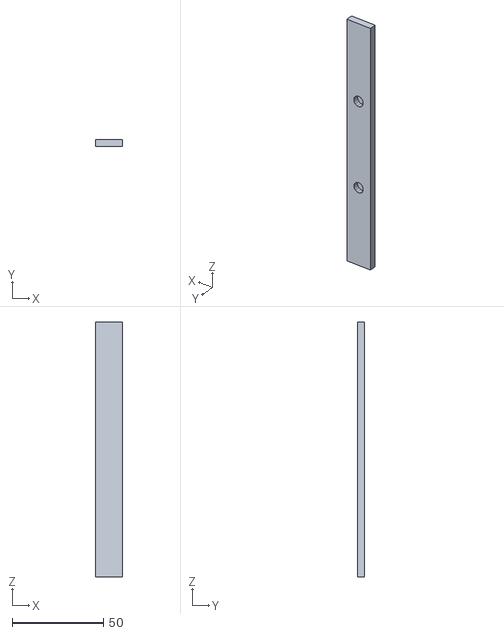
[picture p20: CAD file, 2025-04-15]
Hardware/Enclosure/box_long_edge_just_magnets.stl
15.0 x 4.00 x 140.0

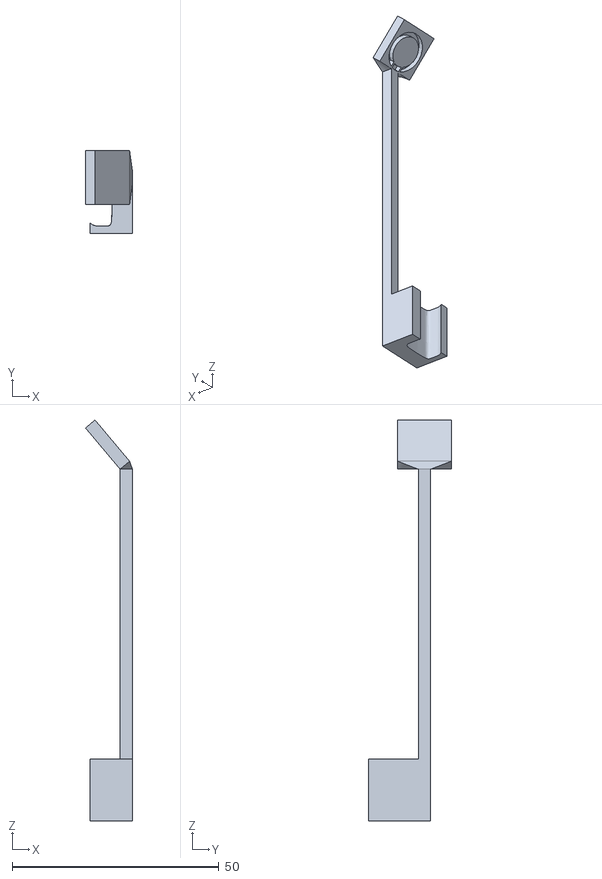
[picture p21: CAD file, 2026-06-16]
Hardware/glasses/boom_arm.stl
11.4 x 20.0 x 96.9

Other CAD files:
Hardware/Enclosure/Baseplate_for_PCBs_mirroredHole.stp
Hardware/glasses/rclamp.stl
Hardware/glasses/NEON_Bare_Metal_Nest_interface.step
Hardware/Enclosure/box_corner_just_magnets.stl
Hardware/Enclosure/Baseplate_for_PCBs_mirroredHoles.ipt
Hardware/Enclosure/Baseplate_for_PCBs_mirroredHoles_smallSection.ipt
Hardware/Enclosure/Baseplate_for_PCBs_v3.ipt
Hardware/Enclosure/Baseplate_for_PCBs_v3_section.ipt
Hardware/Enclosure/OldVersions/Baseplate_for_PCBs_mirroredHole.stp
Hardware/Enclosure/OldVersions/Baseplate_for_PCBs_mirroredHoles.ipt
Hardware/Enclosure/OldVersions/Baseplate_for_PCBs_mirroredHoles_smallSection.ipt
Hardware/Enclosure/OldVersions/Baseplate_for_PCBs_v2.0004.ipt
Hardware/Enclosure/OldVersions/Baseplate_for_PCBs_v2.ipt
Hardware/Enclosure/OldVersions/Baseplate_for_PCBs_v2_section.0002.ipt
Hardware/Enclosure/OldVersions/Baseplate_for_PCBs_v2_section.ipt
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

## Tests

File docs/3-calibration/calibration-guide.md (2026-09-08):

# Optical Calibration Guide

Quantitative visual neuroscience and psychophysics require precise radiometric and photometric calibration. Because LEDs and driver electronics exhibit physical non-linearities, and because biological photoreceptors respond to absorbed photons rather than raw electrical or human-photopic metrics, calibration is divided into two distinct, essential pillars:

```mermaid
flowchart LR
    subgraph Aspect1["1. Max Luminance & Channel Matching"]
        direction TB
        A1["<b>Define Target Regime</b><br/>Scotopic / Mesopic / Photopic"]
        A2["<b>Calculate Target R*</b><br/>e.g. 10⁴ R*/cone/s"]
        A3["<b>Target Power P_meas</b><br/>Ocular media & sensor calibration"]
        A4["<b>Hardware Adjustment</b><br/>Trimpots set 100% DC to match P_meas"]
        A1 --> A2 --> A3 --> A4
    end

    subgraph Aspect2["2. Gamma Correction & Linearization"]
        direction TB
        B1["<b>Automated Duty Sweep</b><br/>'gc, stepSize, waitTime, nReps'"]
        B2["<b>Temporal Power Averaging</b><br/>Avoid PWM carrier aliasing"]
        B3["<b>MATLAB Inversion Pipeline</b><br/>cummax() filter & interp1()"]
        B4["<b>Deploy Gamma LUT</b><br/>Linear stimulus transfer (R² > 0.999)"]
        B1 --> B2 --> B3 --> B4
    end

    Aspect1 ==>|Calibrated Baseline| Aspect2
```

---

## The Two Core Pillars of Calibration

### 1. Max Luminance Configuration & Channel Matching

The first aspect of calibration establishes the **absolute dynamic range** of the stimulator:

* **Biologically Meaningful Channel Matching:** Rather than matching channels by electrical power ($\text{mW}$) or radiometric flux ($\mu\text{W}$), we balance channels according to their biological effect—specifically, their **photoisomerisation rates ($R^*$)** in target photoreceptors (e.g. matching Green LED activation of M-cones with UV LED activation of S-cones).
* **Adaptation Level Control:** By setting the maximum luminance ceiling (100% duty cycle), you place the subject's retina into the desired physiological regime:
    * **Scotopic (Rod-dominated):** $< 10^1 \, R^*/\text{rod/s}$
    * **Mesopic (Rod & Cone active):** $10^1 - 10^3 \, R^*/\text{photoreceptor/s}$
    * **Photopic (Cone-dominated, rods saturated):** $10^3 - 10^5+ \, R^*/\text{cone/s}$
* **Hardware Execution:** Because the LEDs operate at constant continuous DC at 100% duty cycle during this step, max luminance calibration can be measured cleanly with a standard optical power meter or photodiode. The operator turns the multi-turn trimpots (analog gate potentiometers on the driver board) or selects series current-limiting resistors until the exact target power level is measured.

---

### 2. Gamma Correction & Output Linearization

The second aspect of calibration ensures that **commanded stimulus intensities scale linearly**:

* **Sources of Non-Linearity:** Microcontroller PWM duty cycle does not produce a perfectly linear optical output. Non-linearities arise from:
    * Transistor switching characteristics (base-emitter $V_{\text{BE}}$ or gate threshold voltages, junction capacitance, charge storage time, and turn-on delays).
    * LED dynamic forward resistance ($V_f - I_f$) near the turn-on knee.
    * Switching rise and fall transition times at high PWM frequencies ($10-31\text{ kHz}$).
    * Optical diffusion and back-reflections in the ganzfeld dome or goggles.
* **Automated Stepping (`gc`):** The microcontroller firmware provides a dedicated serial command (`gc`) that automatically steps sequentially through duty cycles (e.g., from 0% to 100% in 2% steps) with programmable dwell times and repetitions. (A pseudorandom duty cycle order is planned for future firmware versions to eliminate junction heating hysteresis).
* **Temporal Averaging (Anti-Aliasing):** When operating at $<100\%$ duty cycle, the light output is pulsed at the PWM carrier frequency. Instantaneous sampling can alias into the PWM waveform, introducing severe noise. The measurement device (optical power meter or photodiode DAQ) must perform **temporal averaging** over a steady window (e.g., 2–3 seconds per step) to capture the true time-averaged optical power.
* **Look-Up Table (LUT) Inversion:** The measured power-vs-duty-cycle curve is monotonically filtered and inverted in MATLAB to produce a Look-Up Table (LUT) stored in microcontroller flash memory (`PROGMEM`) or uploaded dynamically.

---

## Calibration Metric: Why Photoisomerisation Rates?

When choosing a calibration target, several metrics exist:

| Calibration Metric | Units | Limitations in Visual Neuroscience | Used Here? |
| :--- | :--- | :--- | :---: |
| **Radiometric Power / Irradiance** | $\mu\text{W}$, $\mu\text{W}/\text{cm}^2$ | Treats all wavelengths equally. Ignores opsin spectral sensitivity, ocular transmission, and photoreceptor geometry. | ❌ (Raw measurement only) |
| **Photometric Illuminance / Luminance** | $\text{lux}$, $\text{cd}/\text{m}^2$ | Weighted exclusively by the *human photopic luminous efficiency curve* ($V(\lambda)$, peaking at 555 nm). Completely invalid for mouse vision and UV stimulation ($365-400\text{ nm}$). | ❌ |
| **Estimated Photoisomerisation Rate ($R^*$)** | $R^*/\text{photoreceptor/s}$ | Quantifies the actual rate at which opsin photopigment molecules absorb photons and isomerise, accounting for pre-retinal ocular transmission, pupil size, detector responsivity, and outer segment collection area. | **✔️ YES (Euler Lab OVS Framework)** |

We follow the biophysical formulation developed by Euler Lab in the [Open Visual Stimulator](https://github.com/eulerlab/open-visual-stimulator) project. See the [Photoreceptor Calculations Guide](photoreceptor-calculations.md) for the complete mathematical derivation and script walkthrough of [`Calibration/ganzfeldCalibration_v5.m`](file:///d:/Code/LEDStimulation/Calibration/ganzfeldCalibration_v5.m).

---

## Calibration Equipment & Setup

```mermaid
flowchart TD
    subgraph Hardware["⚡ Stimulation Hardware"]
        direction LR
        Arduino["<b>Microcontroller</b><br/><i>ATmega32U4 / Teensy</i>"]
        Driver["<b>Driver Board</b><br/><i>Multi-Turn Trimpots</i>"]
        LEDs["<b>Calibrated LEDs</b><br/><i>UV (365nm) & Green (525nm)</i>"]
        Enclosure["<b>Ganzfeld / Goggles</b><br/><i>Diffusion Optics</i>"]
        Arduino --> Driver --> LEDs --> Enclosure
    end

    subgraph Detection["🔬 Optical Detection (Pupil Plane)"]
        direction LR
        Sensor["<b>Optical Sensor</b><br/><i>Photodiode / S121C Sensor</i>"]
        Meter["<b>Power Meter Console / DAQ</b><br/><i>PM100D / PM400</i>"]
        Sensor --> Meter
    end

    subgraph Software["💻 Automated Calibration Software"]
        direction LR
        MATLAB["<b>MATLAB Calibration Suite</b><br/><i>ganzfeldCalibration_v5.m</i>"]
        Serial["<b>Serial Protocol</b><br/><i>'gc' / 'ana' / 'dac'</i>"]
        MATLAB --> Serial
    end

    Enclosure --> Sensor
    Meter --> MATLAB
    Serial --> Arduino
```

### Sensor Options

1. **Option 1 (Standard): Optical Power Meter Console + Calibrated Sensor**
    * **Console:** Thorlabs PM100D, PM100USB, or PM400.
    * **Sensor:** Calibrated photodiode sensor covering UV and Visible wavelengths (e.g., **Thorlabs S121C**, **S120VC**, or **S130VC**).
    * *Advantage:* Built-in power calibration, internal integration/averaging, direct USB/serial communication with MATLAB.
2. **Option 2 (High-Speed / DAQ): Amplified Si Photodiode**
    * **Sensor:** Thorlabs **PDA100A2** switchable-gain amplified photodiode connected to a National Instruments DAQ or oscilloscope.
    * *Gain Setting:* Set transimpedance gain (e.g., $70\text{ dB}$, $2.38 \times 10^6\text{ V/A}$).
    * *Averaging:* Apply software low-pass filtering or window averaging to eliminate PWM carrier ripple.

### Physical Alignment

* Mount the sensor active area at the **exact spatial plane of the subject's eye / retina** relative to the diffuser surface.
* Seal the enclosure against ambient room light. Perform a **dark baseline measurement** ($V_{\text{dark}}$ or $P_{\text{dark}}$) with all LEDs powered off before proceeding.

---

## Step-by-Step Calibration Procedure

### Phase 1: Max Luminance Matching (Trimpot Adjustment at 100% Duty Cycle)

1. **Calculate Target Power:**
   Open [`Calibration/ganzfeldCalibration_v5.m`](file:///d:/Code/LEDStimulation/Calibration/ganzfeldCalibration_v5.m). Enter your target photoisomerisation rates $R^*_{\text{target}}$ (e.g. $10^4\,R^*/\text{cone/s}$). The script works backwards to compute the target power meter reading $P_{\text{meas}}$ in $\mu\text{W}$ at your chosen meter wavelength setting $\lambda_{\text{meas}}$ (e.g. $525\text{ nm}$ for Green, $370\text{ nm}$ for UV).
2. **Isolate Channel A:**
   Enable Channel A at 100% duty cycle:
   ```text
   sd, 100, 0
   ```
   *(or use `useChB 0` followed by `sd, 100, 0`).*
3. **Tune Channel A Trimpot:**
   Using an insulated ceramic screwdriver, adjust the multi-turn trimpot for Channel A on the driver PCB until the power meter reads the exact target $P_{\text{meas}}$ calculated in Step 1.
4. **Isolate Channel B:**
   Enable Channel B at 100% duty cycle:
   ```text
   sd, 0, 100
   ```
   *(or use `useChA 0` followed by `sd, 0, 100`).*
5. **Tune Channel B Trimpot:**
   Adjust the multi-turn trimpot for Channel B until the power meter reads the exact target $P_{\text{meas}}$ for Channel B.
6. **Record Potentiometer Settings:**
   Optionally send the `ana` command to stream analog monitor voltages on pins `A0`/`A1`, and record the final values in [`PotentiometerSettingsNotes.txt`](file:///d:/Code/LEDStimulation/PotentiometerSettingsNotes.txt).

---

### Phase 2: Automated Gamma Sweep & Temporal Averaging

1. **Initialize Sensor Logging:**
   Configure your power meter or DAQ to record time-series power measurements at $\ge 10-100\text{ Hz}$.
2. **Execute Automated Gamma Sweep (`gc`):**
   Send the gamma calibration command via serial:
   ```text
   gc, 0.02, 5000, 3
   ```
   *Parameters:*
   * `stepSize = 0.02`: Steps duty cycle in 2% increments (51 levels from 0.0 to 1.0).
   * `waitTime = 5000`: Dwells at each duty cycle for $5000\text{ ms}$ (5 seconds).
   * `nReps = 3`: Repeats the full sweep 3 times for averaging.
3. **Temporal Averaging Window:**
   In MATLAB ([`Calibration/generateGammaCorrectionLUT.m`](file:///d:/Code/LEDStimulation/Calibration/generateGammaCorrectionLUT.m)), segment each 5-second step:
   * Discard the first $1000\text{ ms}$ (transient/settling time).
   * Compute the **median power** over the remaining $3000-4000\text{ ms}$ window to reject instantaneous PWM fluctuations.

---

### Phase 3: LUT Generation & Firmware Deployment

1. **Compute Monotonic Inverse in MATLAB:**
   Run [`Calibration/generateGammaCorrectionLUT.m`](file:///d:/Code/LEDStimulation/Calibration/generateGammaCorrectionLUT.m). The script:
   * Normalizes brightness to $[0, 1]$.
   * Enforces strict monotonicity using `cummax()`.
   * Inverts the transfer function using `interp1()` onto an ideal linear grid ($0 \dots 1040$ for Leonardo DDS or $0 \dots 255$ for 8-bit registers).
2. **Export C Array:**
   The script exports a formatted C code array header (e.g., `const uint16_t PROGMEM LUT[1041] = { ... };`).
3. **Embed in Firmware:**
   * Copy the generated array into your firmware sketch (e.g. [`ArduinoCode/StimulusControlViaSerial_Leonardo_DDS_8bit_2freq/`](file:///d:/Code/LEDStimulation/ArduinoCode/StimulusControlViaSerial_Leonardo_DDS_8bit_2freq/)).
   * Flash the updated firmware to the microcontroller.
   * If using Teensy 4.1, use the `loadlut` command to upload the table dynamically over serial.
4. **Verification:**
   Repeat a brief duty-cycle sweep with gamma correction enabled (`agc, 1`) and verify that measured optical power scales with $R^2 > 0.999$ linearity against requested stimulus intensity.

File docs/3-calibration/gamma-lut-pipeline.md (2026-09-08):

# Gamma Correction LUT Pipeline

Even when the peak forward current is calibrated, pulse-width modulated (PWM) optical output does not scale linearly with requested duty cycle. To achieve true radiometric and photometric linearity, the system uses Look-Up Tables (LUTs) stored in microcontroller Flash memory (`PROGMEM`) or uploaded dynamically to runtime RAM.

```mermaid
flowchart LR
    subgraph Acq["1. Optical Data Acquisition"]
        direction TB
        Cmd["<b>Sweep Command</b><br/>'gc, 0.02, 5000, 3'"]
        MCU["<b>Microcontroller Duty Sweep</b><br/>Steps 0% to 100%"]
        Sens["<b>Optical Sensor + DAQ</b><br/>Thorlabs PM100D / PDA100A2"]
        Avg["<b>Temporal Averaging</b><br/>Eliminate PWM carrier ripple"]
        Cmd --> MCU --> Sens --> Avg
    end

    subgraph Proc["2. MATLAB Curve Inversion"]
        direction TB
        Load["<b>Extract Median Power</b><br/>Discard 1s step transients"]
        Norm["<b>Normalize to [0, 1]</b><br/>Enforce cummax() monotonicity"]
        Invert["<b>Inverse Interpolation</b><br/>interp1() to linear target"]
        Scale["<b>Scale to Register Bits</b><br/>0..1040 for 16-bit PWM"]
        Load --> Norm --> Invert --> Scale
    end

    subgraph Embed["3. Firmware Deployment"]
        direction TB
        GenC["<b>Export C LUT Array</b><br/>uint16_t PROGMEM LUT[1041]"]
        Flash["<b>Flash Microcontroller</b><br/>Header embedding or 'loadlut'"]
        Verify["<b>Linearity Validation</b><br/>Verify post-cal R² > 0.999"]
        GenC --> Flash --> Verify
    end

    Acq ==> Proc ==> Embed
```

---

## 1. Physical Causes of Non-Linearity

```mermaid
flowchart TD
    subgraph Electrical["Physical Sources of Non-Linearity"]
        direction LR
        Transistor["<b>Transistor Dynamics</b><br/>V_BE and gate charge delays"]
        Knee["<b>LED Diode Knee</b><br/>Non-linear Vf-If resistance"]
        Slew["<b>Switching Slew Rates</b><br/>Pulse asymmetry at &lt;2% duty"]
    end
    Electrical --> Distortion["<b>Distorted Optical Output vs Duty Cycle</b><br/><i>(Fully linearized via Calibrated Gamma LUT)</i>"]
```

1. **Transistor Switching Characteristics:** At low duty cycles (e.g. $< 5\%$), drive pulses may not fully saturate the driver transistors (e.g. bipolar junction transistors, FETs, or buffer stages) before the falling edge arrives. Base-emitter turn-on voltages ($V_{\text{BE}}$), gate thresholds, junction capacitance, and charge storage times introduce non-linear turn-on behavior and pulse-width distortion.
2. **LED Dynamic Forward Resistance ($V_f - I_f$):** As current increases, the internal diode dynamic resistance shifts the operating point, producing minor non-linearities in luminous efficacy.
3. **Switching Rise/Fall Transitions:** Finite switching rise and fall times introduce pulse asymmetry at microsecond PWM timescales ($10-31\text{ kHz}$ carrier frequencies).
4. **Optical Back-Reflections & Diffusion:** Diffusers and dome geometries cause subtle non-linear back-scattering at high optical power levels.

---

## 2. Automated Measurement Sweep (`gc`)

The microcontroller firmware contains an automated stepping routine (`cycleDutyCycles`) triggered by the serial command `gc`:

```text
gc, <stepSize>, <waitTime_ms>, <nReps>
```

### Example Command
```text
gc, 0.02, 5000, 3
```

| Parameter | Example Value | Description |
| :--- | :---: | :--- |
| `stepSize` | `0.02` | Duty cycle step increment as a fraction ($0.02 = 2\%$ steps $\rightarrow 51$ test points from $0.0$ to $1.0$). |
| `waitTime_ms` | `5000` | Dwell duration at each duty cycle in milliseconds ($5000\text{ ms} = 5\text{ s}$). |
| `nReps` | `3` | Number of complete repetitions of the sweep to average over. |

During the sweep, the firmware outputs each duty cycle value over serial, sets the hardware OCR compare registers, pauses for `waitTime_ms`, and emits `-1` upon completion before restoring the default 50% baseline.

*(Note: Current firmware steps sequentially through duty cycles; pseudorandom duty cycle presentation is planned for future firmware versions to eliminate potential junction heating hysteresis).*

---

## 3. Temporal Averaging & Anti-Aliasing

!!! critical "Crucial Anti-Aliasing Requirement"
    When operating at **$< 100\%$ duty cycles**, the LED light output is rapidly pulsed at the PWM carrier frequency ($10\text{ kHz} - 31.25\text{ kHz}$).
    
    If the optical sensor samples instantaneously at discrete points without temporal integration, the readings will **alias into the high-frequency PWM switching waveform**, resulting in massive noise and corrupt calibration data.

### Best Practices for Signal Acquisition:
1. **Thorlabs Optical Power Meters (PM100D, PM100USB, PM400):**
   These consoles have internal analog bandwidth filtering and digital integration, naturally providing clean time-averaged power readings.
2. **Amplified Photodiodes (PDA100A2 + DAQ):**
   * Apply an analog low-pass filter (e.g. $100\text{ Hz}$ cutoff) or set the DAQ sampling rate to $\ge 100\text{ kHz}$ and compute boxcar/block averages over 1-second windows.
3. **MATLAB Steady-State Windowing:**
   In [`Calibration/generateGammaCorrectionLUT.m`](file:///d:/Code/LEDStimulation/Calibration/generateGammaCorrectionLUT.m), power is extracted by:
   * Waiting $1000\text{ ms}$ after each step transition to allow electronic and thermal stabilization.
   * Computing the **median optical power** over the remaining $3000-4000\text{ ms}$ steady-state window.

---

## 4. MATLAB Processing & Curve Inversion

The script [`Calibration/generateGammaCorrectionLUT.m`](file:///d:/Code/LEDStimulation/Calibration/generateGammaCorrectionLUT.m) processes the sweep data through the following steps:

```matlab
% 1. Extract steady-state median power for each duty cycle
for icycle = 1:numel(dutyCyclesOrig)
    temp_startTime = startTime + waitTime*(icycle-1) + delayTime;
    temp_endTime   = temp_startTime + takeValsDuration;
    temp_idx = find(power_table.Time >= temp_startTime & power_table.Time <= temp_endTime);
    powerValsOrig(icycle) = median(power_table.Power(temp_idx));
end

% 2. Normalize measured brightness to [0, 1]
measured_brightness = powerValsOrig / max(powerValsOrig);

% 3. Enforce strict monotonicity (optical power must never decrease with duty cycle)
monotonic_brightness = cummax(measured_brightness);

% 4. Remove duplicate brightness levels to ensure bijective interpolation
[unique_brightness, unique_idx] = unique(monotonic_brightness, 'stable');
unique_duty_cycle = dutyCyclesOrig(unique_idx);

% 5. Create ideal linear target grid (e.g., 1041 levels for Timer 1 DDS)
num_levels = 1041;
target_brightness = linspace(0, 1, num_levels);

% 6. Invert the transfer function: map target brightness -> required duty cycle
corrected_pixel_values = interp1(unique_brightness, unique_duty_cycle, target_brightness, 'linear', 'extrap');

% 7. Scale to timer register units and enforce boundaries
LUT = round(corrected_pixel_values * (num_levels - 1) / 100);
LUT = max(0, min(num_levels - 1, LUT)); % Clip to [0, 1040]
LUT = cummax(LUT);                      % Guarantee non-decreasing
LUT(1) = 0;                             % Guarantee absolute zero when off
```

---

## 5. Resolution Scaling & Architecture Mapping

Different firmware architectures and timer resolutions require different LUT table lengths:

| Architecture | Firmware Sketch | Timer Mode | Resolution | LUT Table Length | Script |
| :--- | :--- | :--- | :---: | :---: | :--- |
| **Arduino Leonardo DDS** | `StimulusControlViaSerial_Leonardo_DDS_8bit_2freq.ino` | Timer 1 (16-bit, TOP=1040) | $10.02\text{ bit}$ | **$1041$ entries** | `generateGammaCorrectionLUT.m` |
| **Arduino Leonardo 8-bit** | `StimulusControlViaSerial_Leonardo_v8.ino` | Timer 1 / 4 (8-bit, TOP=255) | $8\text{ bit}$ | **$256$ entries** | `mapLUTs.m` |
| **Teensy 4.1 FlexPWM** | `LEDStimController_Teensy41_DDS.ino` | FlexPWM Submodules | $16\text{ bit}$ | **$65536$ entries** (or interpolated $1024$) | Dynamic upload |

### Multi-Architecture Fractional Conversion (`mapLUTs.m`)

The script [`Calibration/mapLUTs.m`](file:///d:/Code/LEDStimulation/Calibration/mapLUTs.m) allows high-resolution calibration curves to be scaled to 8-bit or 16-bit microcontrollers using Piecewise Cubic Hermite Interpolating Polynomials (`pchip`), evaluating quantization deviation:

```matlab
% Convert normalized geometric curve to 8-bit scale
fractional_curve = interp1(linspace(0, 1, 1041), ChA1LUT_orig / 1040, linspace(0, 1, 256), 'pchip');
ChA1LUT_8bit = round(fractional_curve * 255);
ChA1LUT_8bit = max(0, min(255, ChA1LUT_8bit));
```

---

## 6. Embedding in Firmware & Dynamic Loading

### Option A: Static Compilation in Flash (`PROGMEM`)

[`generateGammaCorrectionLUT.m`](file:///d:/Code/LEDStimulation/Calibration/generateGammaCorrectionLUT.m) exports formatted C header arrays:

```cpp
// Stored in microcontroller flash memory to conserve SRAM
const uint16_t PROGMEM ChA_LUT[1041] = {
    0, 2, 5, 8, 11, 14, 18, 22, 26, 30,
    34, 38, 43, 47, 52, 57, 62, 67, 72, 77,
    ...
    1020, 1025, 1030, 1035, 1040
};
```

* Embed this table directly into your sketch.
* At runtime, use `agc, 1` to enable gamma correction or `agc, 0` to bypass.

### Option B: Dynamic Serial Upload (`loadlut` on Teensy 4.1)

For Teensy 4.1 firmware ([`ArduinoCode/LEDStimController_Teensy41_DDS/`](file:///d:/Code/LEDStimulation/ArduinoCode/LEDStimController_Teensy41_DDS/)), LUTs can be streamed directly over USB Serial into RAM without recompiling firmware:

```text
loadlut, <channel>, <val0>, <val1>, <val2>, ...
```

---

## 7. Verification & Linearity Validation

After flashing the calibrated LUT:
1. Re-run an automated duty cycle sweep with gamma correction enabled (`agc, 1`).
2. Plot measured optical power ($\mu\text{W}$) against commanded stimulus amplitude ($0.0 \dots 1.0$).
3. Perform linear regression ($y = m \cdot x + c$). A successful calibration yields $R^2 \ge 0.999$, ensuring distortion-free sinusoidal, chirp, and pulse stimulus rendering.

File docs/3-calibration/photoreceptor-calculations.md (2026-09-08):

# Photoreceptor Quantification & Spectral Calculations

To achieve biologically meaningful visual stimulation in neuroscience and psychophysics, optical power emitted by the LEDs must be quantified in terms of **photoisomerisation rates ($R^*$)** per photoreceptor type per second ($\text{isomerisations}/\text{photoreceptor}/\text{s}$, or $10^3\,R^*$).

This page provides a complete walkthrough of the calibration script [`Calibration/ganzfeldCalibration_v5.m`](file:///d:/Code/LEDStimulation/Calibration/ganzfeldCalibration_v5.m), which implements the biophysical framework developed by Euler Lab in the [Open Visual Stimulator](https://github.com/eulerlab/open-visual-stimulator) project.

---

## Calibration Logic & Workflow

The calibration mathematics connects biological target regimes to physical bench measurements through two directional flows:

### 1. Forward Calculation (Data Analysis in MATLAB)
Converts an empirical optical power meter or photodiode reading into absolute photoisomerisation rates ($R^*$):

$$\text{Power Meter Reading } P_{\text{meas}} \xrightarrow{C_{\text{factor}}} \text{True Radiant Power } P_{\text{true}} \xrightarrow{T_{\text{eye}}, \, \frac{A_{\text{pupil}}}{A_{\text{retina}}}} \text{Retinal Power } P_{\text{retina}} \xrightarrow{S_{\text{opsin}}, \, a_c} \text{Isomerisation Rate } R^*$$

* **Purpose:** Quantifies exactly how many photoisomerisations per cone or rod per second are elicited by the current stimulator output.
* **Implementation:** Executed automatically by [`Calibration/ganzfeldCalibration_v5.m`](file:///d:/Code/LEDStimulation/Calibration/ganzfeldCalibration_v5.m).

### 2. Inverse Calculation (Experimental Bench Calibration)
Works backwards from a desired physiological adaptation state to determine the required reading on the power meter console:

$$\text{Target Rate } R^*_{\text{target}} \longrightarrow \text{Required True Power } P_{\text{true}} \longrightarrow \text{Target Meter Reading } P_{\text{meas}} \longrightarrow \text{Hardware Trimpot Adjustment}$$

* **Purpose:** Tells the experimenter the exact target reading ($\mu\text{W}$) to set on the Thorlabs power meter console when adjusting the driver board potentiometers at 100% duty cycle.
* **Linear Scaling:** Because the forward transfer function from radiant power to photoisomerisation rate is strictly linear, the inverse mapping is an exact scalar proportionality.

---

## 1. Physical Constants & Biological Parameters

The calculations in [`ganzfeldCalibration_v5.m`](file:///d:/Code/LEDStimulation/Calibration/ganzfeldCalibration_v5.m) rely on physical constants and experimentally verified mouse ocular properties:

### Physical Constants

| Variable | MATLAB Name | Value | Unit | Description |
| :--- | :--- | :--- | :--- | :--- |
| $h$ | `h` | $4.135667 \times 10^{-15}$ | $\text{eV}\cdot\text{s}$ | Planck's constant |
| $c$ | `c` | $299,792,458$ | $\text{m/s}$ | Speed of light in vacuum |
| — | `eV_per_J` | $6.242 \times 10^{18}$ | $\text{eV/J}$ | Conversion factor from Joules to electron-volts |

### Photoreceptor Parameters (Mouse)

Photoreceptor opsin absorbance profiles are loaded from [`Calibration/mouse_cone_opsins.txt`](file:///d:/Code/LEDStimulation/Calibration/mouse_cone_opsins.txt):

| Photoreceptor | MATLAB Name | Peak Wavelength ($\lambda_{\text{peak}}$) | End-on Collection Area ($a_c, a_r$) | Sensitivity Profile ($S_{\text{PR}}(\lambda)$) | Reference |
| :--- | :--- | :---: | :---: | :--- | :--- |
| **M-cone** | `mouse_M_cone` | $511\text{ nm}$ | $0.2\,\mu\text{m}^2$ | `mouse_opsins.Mopsin` | Nikonov et al., 2006 |
| **S-cone** | `mouse_S_cone` | $360\text{ nm}$ | $0.2\,\mu\text{m}^2$ | `mouse_opsins.Sopsin` | Nikonov et al., 2006 |
| **Rod** | `mouse_rod` | $510\text{ nm}$ | $0.5\,\mu\text{m}^2$ | `mouse_opsins.Mopsin` | Nikonov et al., 2006 |

!!! note "Collection Area ($a_c, a_r$)"
    The end-on light collection area ($a_c = 0.2\,\mu\text{m}^2$ for dark-adapted wt mouse cones, $a_r = 0.5\,\mu\text{m}^2$ for rods) represents the effective physical cross-section through which incoming photons are captured and absorbed by outer segment opsin molecules.

<figure markdown="span" style="max-width: 520px; margin: 1.5em auto; text-align: center;">
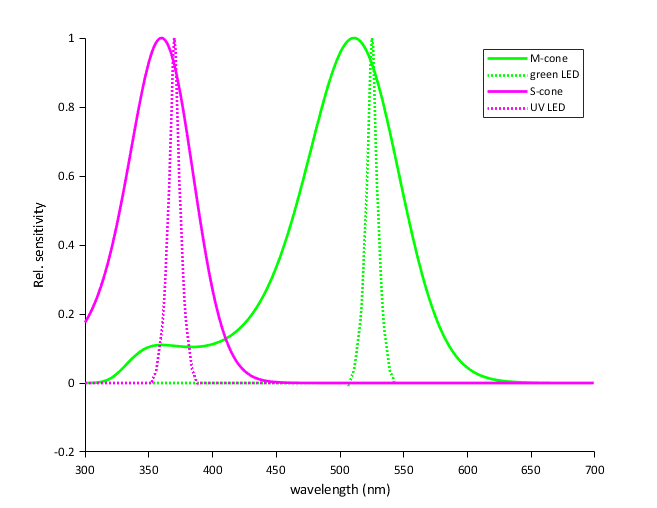
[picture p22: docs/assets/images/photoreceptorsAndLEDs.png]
Photoreceptor Sensitivity and LED Emission Spectra
  
  <figcaption style="font-size: 0.85em; color: var(--md-default-fg-color--light); margin-top: 0.5em;"><strong>Figure 1:</strong> Relative spectral sensitivity of mouse M-cone (green solid) and S-cone (magenta solid) opsins alongside peak-normalized emission spectra of the Green LED (green dotted) and UV LED (magenta dotted).</figcaption>
</figure>

### Ocular & Anatomical Properties

* **Pre-retinal Ocular Transmission ($T_{\text{eye}}(\lambda)$):** Loaded from [`Calibration/Transmission_mouse_eye.txt`](file:///d:/Code/LEDStimulation/Calibration/Transmission_mouse_eye.txt), accounting for wavelength-dependent absorption by the cornea, crystalline lens, and vitreous humor (especially significant in the near-UV band $< 400\text{ nm}$).
* **Pupil Area ($A_{\text{pupil}}$):**
    * Stationary state: $A_{\text{pupil}} \approx 0.21\,\text{mm}^2$
    * Running / Dilated state: $A_{\text{pupil}} \approx 1.91\,\text{mm}^2$
* **Retinal Surface Area ($A_{\text{retina}}$):**
    For an adult mouse eye with axial length $d = 3.0\text{ mm}$ ($r = 1.5\text{ mm}$):

    $$A_{\text{retina}} \approx 0.6 \cdot \pi \cdot d^2 = 0.6 \cdot \pi \cdot (3.0\,\text{mm})^2 \approx 16.96\,\text{mm}^2$$

* **Pupil-to-Retina Geometric Ratio:**

    $$k_{\text{pupil}} = \frac{A_{\text{pupil}}}{A_{\text{retina}}} = \frac{1.91\,\text{mm}^2}{16.96\,\text{mm}^2} \approx 0.1126$$

### Sensor Parameters

* **Thorlabs Photodiode Sensor (S121C, S120VC, S130VC):**
    * Active Sensor Area: $A_{\text{detect}} = 9700\,\mu\text{m} \times 9700\,\mu\text{m} = 94.09 \times 10^6\,\mu\text{m}^2 = 94.09\,\text{mm}^2$
    * Calibrated responsivity curve $R(\lambda)$ loaded from `Calibration/PowerMeterCalibrationFiles/`.
* **Thorlabs PDA100A2 Amplified Sensor:**
    * Active Sensor Area: $A_{\text{detect}} = 75.4 \times 10^6\,\mu\text{m}^2 = 75.4\,\text{mm}^2$

---

## 2. Forward Calculation: Power Meter to $R^*$

Here is the exact mathematical sequence executed in [`Calibration/ganzfeldCalibration_v5.m`](file:///d:/Code/LEDStimulation/Calibration/ganzfeldCalibration_v5.m):

### Step 1: Broad-Band Sensor Responsivity Correction

Optical power meters (such as the Thorlabs PM100D) compute power by dividing the measured detector photocurrent by the sensor responsivity at a single user-entered calibration wavelength: $R(\lambda_{\text{meas}})$. Because LEDs have a broad spectral emission $S(\lambda)$ (typically $20-40\text{ nm}$ FWHM), the raw meter reading $P_{\text{meas}}$ is biased.

The true radiant power $P_{\text{true}}$ is recovered using [`Calibration/getLEDSpectraFromPowerMeter.m`](file:///d:/Code/LEDStimulation/Calibration/getLEDSpectraFromPowerMeter.m):

$$C_{\text{factor}} = \frac{R(\lambda_{\text{meas}}) \int S(\lambda) \, d\lambda}{\int S(\lambda) R(\lambda) \, d\lambda}$$

$$P_{\text{true}} = P_{\text{meas}} \cdot C_{\text{factor}}$$

The absolute spectral power distribution $P(\lambda)$ across 1-nm bins ($\Delta\lambda = 1\text{ nm}$) from $300\text{ nm}$ to $699\text{ nm}$ is:

$$P(\lambda) = P_{\text{true}} \cdot \frac{S(\lambda)}{\int S(\lambda) \, d\lambda} \quad [\text{W/nm}]$$

<figure markdown="span" style="max-width: 500px; margin: 1.5em auto; text-align: center;">
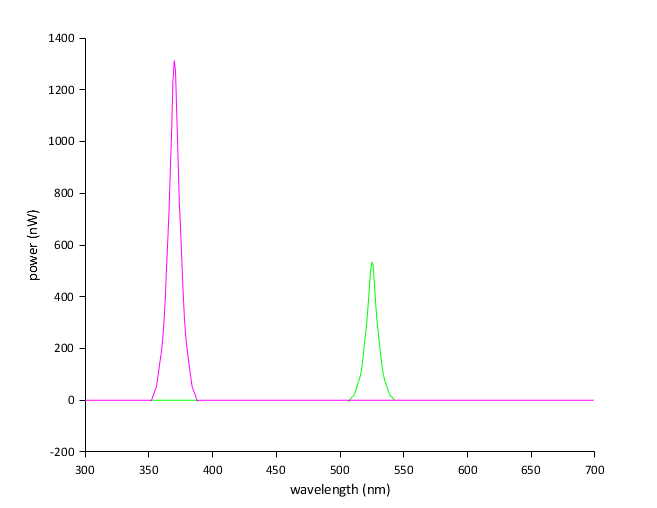
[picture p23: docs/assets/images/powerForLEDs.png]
Corrected Spectral Power of LEDs
  
  <figcaption style="font-size: 0.85em; color: var(--md-default-fg-color--light); margin-top: 0.5em;"><strong>Figure 2:</strong> Responsivity-corrected spectral radiant power ($P(\lambda)$ in $\text{nW}$) for the Green and UV channels.</figcaption>
</figure>

!!! tip "Alternative: PDA100A2 Amplified Photodiode"
    If using the PDA100A2 transimpedance photodiode ([`Calibration/getLEDSpectraFromPhotodiode.m`](file:///d:/Code/LEDStimulation/Calibration/getLEDSpectraFromPhotodiode.m)):

    $$I_p = \frac{V_{\text{measured}} - V_{\text{dark}}}{\text{Gain}_{\text{Hi-Z}}} \quad [\text{Amperes}]$$

    $$R_{\text{eff}} = \frac{\int S(\lambda) R(\lambda) \, d\lambda}{\int S(\lambda) \, d\lambda} \quad [\text{A/W}]$$

    $$P_{\text{true}} = \frac{I_p}{R_{\text{eff}}} \quad [\text{Watts}]$$

---

### Step 2: Pre-Retinal Transmission & Retinal Geometry

The spectral power reaching the photoreceptor outer segment layer inside the eye is attenuated by the ocular media $T_{\text{eye}}(\lambda)$ and scaled by the pupil-to-retina area ratio:

$$P_{\text{retina}}(\lambda) = P(\lambda) \cdot T_{\text{eye}}(\lambda) \cdot \left(\frac{A_{\text{pupil}}}{A_{\text{retina}}}\right)$$

---

### Step 3: Spectral Overlap & Relative Co-Excitation

For LED $i$ and photoreceptor type $j$, the relative spectral co-excitation fraction is calculated from the normalized spectral overlap:

$$\text{Co-excitation}_{i,j} = \frac{\int S_{\text{PR}, j}(\lambda) \cdot S_{\text{LED\_corr\_norm}, i}(\lambda) \, d\lambda}{\int S_{\text{LED\_corr\_norm}, i}(\lambda) \, d\lambda}$$

Where $S_{\text{LED\_corr\_norm}, i}(\lambda)$ is the peak-normalized retinal LED spectrum.

---

### Step 4: Photon Energy, Photon Flux Density & Isomerisation Rate

1. **Wavelength-dependent photon energy ($Q(\lambda)$ in $\text{eV}$):**

    $$Q(\lambda) = \frac{h \cdot c}{\lambda \cdot 10^{-9}}$$

2. **Spectral photon flux ($\Phi_{\text{photon}}(\lambda)$ in $\text{photons/s}$):**

    $$\Phi_{\text{photon}}(\lambda) = \frac{P_{\text{retina}}(\lambda) \cdot (\text{eV\_per\_J})}{Q(\lambda)}$$

3. **Photon flux density arriving at the sensor detector plane ($E(\lambda)$ in $\text{photons}/(\text{s}\cdot\mu\text{m}^2)$):**

    $$E(\lambda) = \frac{\Phi_{\text{photon}}(\lambda)}{A_{\text{detect}}}$$

4. **Total photoisomerisation rate ($R^*$ in $\text{isomerisations}/\text{photoreceptor}/\text{s}$):**

    $$R^*_{i,j} = a_{\text{collect}, j} \cdot \text{Co-excitation}_{i,j} \int E_i(\lambda) \, d\lambda$$

In [`ganzfeldCalibration_v5.m`](file:///d:/Code/LEDStimulation/Calibration/ganzfeldCalibration_v5.m), rates are reported in units of $10^3\,R^*/\text{s}$ ($10^3\,\text{photons/s}$).

<figure markdown="span" style="max-width: 540px; margin: 1.5em auto; text-align: center;">
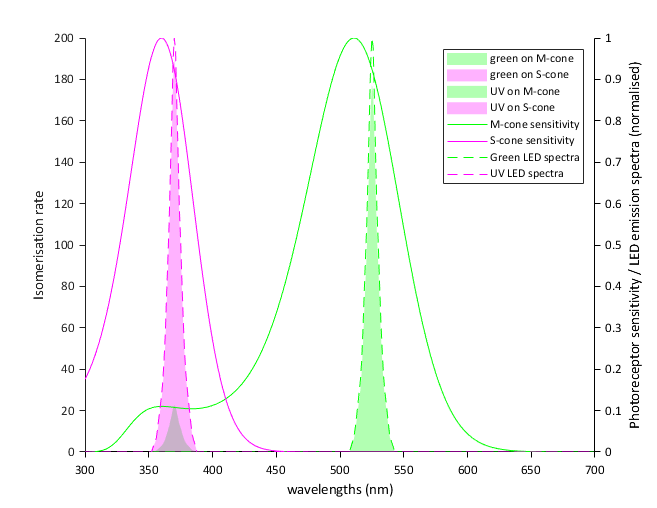
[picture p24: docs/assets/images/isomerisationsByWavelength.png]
Photoisomerisation Rates by Wavelength
  
  <figcaption style="font-size: 0.85em; color: var(--md-default-fg-color--light); margin-top: 0.5em;"><strong>Figure 3:</strong> Calculated spectral photoisomerisation rates ($R^*$ density, left axis shaded areas) across wavelengths for Green and UV channels on M-cones and S-cones, alongside normalized opsin sensitivities (solid lines) and LED emissions (dashed lines, right axis).</figcaption>
</figure>

---

## 3. Working Backwards: From Target $R^*$ to Measured Power

In experimental design, you start with a target photoisomerisation rate $R^*_{\text{target}}$ (e.g. $10^4\,R^*/\text{cone/s}$) and need to determine the **exact power reading to calibrate the hardware to at 100% duty cycle**.

Because the forward pipeline from radiant power to $R^*$ is strictly linear:

$$\frac{R^*}{P_{\text{true}}} = k_{\text{iso}} = \text{constant}$$

### Inverse Calibration Procedure

1. **Run a Reference Calibration in MATLAB:**
   Execute `ganzfeldCalibration_v5.m` with an arbitrary reference power $P_{\text{ref}}$ (e.g. $P_{\text{meas, ref}} = 6.05\,\mu\text{W}$).
   Record the resulting reference photoisomerisation rate $R^*_{\text{ref}}$.
2. **Compute the Required True Power ($P_{\text{true, target}}$):**

    $$P_{\text{true, target}} = P_{\text{true, ref}} \cdot \left(\frac{R^*_{\text{target}}}{R^*_{\text{ref}}}\right)$$

3. **Compute the Target Power Meter Reading ($P_{\text{meas, target}}$):**
   For your power meter console set to wavelength $\lambda_{\text{meas}}$:

    $$P_{\text{meas, target}} = \frac{P_{\text{true, target}}}{C_{\text{factor}}}$$

4. **Physical Adjustment at the Rig:**
   * Set the LED channel to 100% duty cycle (`sd, 100, 0` for Green, `sd, 0, 100` for UV).
   * Turn the channel's multi-turn potentiometer on the driver PCB with an insulated trimmer tool until the console reads exactly $P_{\text{meas, target}}$.

---

### Concrete Worked Numerical Example

Based on the actual calibration values from [`Calibration/ganzfeldCalibration_v5.m`](file:///d:/Code/LEDStimulation/Calibration/ganzfeldCalibration_v5.m) using a Thorlabs S121C sensor ($A_{\text{detect}} = 94.09\,\text{mm}^2$) and running mouse eye geometry ($A_{\text{pupil}} = 1.91\,\text{mm}^2$):

#### Channel A: Green LED ($\lambda_{\text{peak}} \approx 525\text{ nm}$)
* **Measurement Wavelength Setting:** $\lambda_{\text{meas}} = 525\text{ nm}$
* **Sensor Responsivity Correction:** $C_{\text{factor, Green}} \approx 1.018$
* **Target Photoisomerisation Rate:** $R^*_{\text{target, M-cone}} = 25.0 \times 10^3 \, R^*/\text{cone/s}$
* **Calculation:**
    * A power meter reading of $P_{\text{meas}} = 6.05\,\mu\text{W}$ yields $P_{\text{true}} = 6.16\,\mu\text{W}$, producing an M-cone isomerisation rate of $R^* = 25.32 \times 10^3\,R^*/\text{cone/s}$.
    * To set an exact target of $25.0 \times 10^3\,R^*/\text{s}$:

        $$P_{\text{meas, target}} = 6.05\,\mu\text{W} \cdot \left(\frac{25.0}{25.32}\right) = 5.97\,\mu\text{W}$$

* **Action:** Adjust the Green channel trimpot until the PM100D reads **$5.97\,\mu\text{W}$**.

#### Channel B: UV LED ($\lambda_{\text{peak}} \approx 370\text{ nm}$)
* **Measurement Wavelength Setting:** $\lambda_{\text{meas}} = 370\text{ nm}$
* **Sensor Responsivity Correction:** $C_{\text{factor, UV}} \approx 1.042$
* **Target Photoisomerisation Rate:** $R^*_{\text{target, S-cone}} = 25.0 \times 10^3 \, R^*/\text{cone/s}$ (for iso-effective cone stimulation)
* **Calculation:**
    * A power meter reading of $P_{\text{meas}} = 15.0\,\mu\text{W}$ yields $P_{\text{true}} = 15.63\,\mu\text{W}$, producing an S-cone isomerisation rate of $R^* = 26.48 \times 10^3\,R^*/\text{cone/s}$ (after accounting for corneal/lens UV absorption).
    * To achieve an exact match of $25.0 \times 10^3\,R^*/\text{s}$:

        $$P_{\text{meas, target}} = 15.0\,\mu\text{W} \cdot \left(\frac{25.0}{26.48}\right) = 14.16\,\mu\text{W}$$

* **Action:** Adjust the UV channel trimpot until the PM100D reads **$14.16\,\mu\text{W}$**.

---

## 4. Photoreceptor Co-Excitation & Crosstalk Matrix

Because the spectral emission profiles of the LEDs overlap with the absorption spectra of multiple photoreceptors, stimulation is rarely 100% opsin-isolated.

The co-excitation matrix calculated by [`Calibration/ganzfeldCalibration_v5.m`](file:///d:/Code/LEDStimulation/Calibration/ganzfeldCalibration_v5.m) shows the relative activation:

| Stimulus LED | M-Cone ($511\text{ nm}$) Activation | S-Cone ($360\text{ nm}$) Activation | Rod ($510\text{ nm}$) Activation | Primary Target |
| :--- | :---: | :---: | :---: | :--- |
| **Green LED ($525\text{ nm}$)** | **$88.4\%$** | $< 0.1\%$ | $87.1\%$ | **M-cone / Rod** |
| **UV LED ($370\text{ nm}$)** | $4.2\%$ | **$91.6\%$** | $3.9\%$ | **S-cone** |

!!! tip "Opsin-Isolating Contrasts / Silent Substitution"
    Because the Green LED causes negligible excitation of S-cones ($<0.1\%$), green modulation provides clean M-cone and rod stimulation without activating S-cones.
    Conversely, the UV LED exhibits minor co-excitation on M-cones ($\approx 4.2\%$). For strict silent substitution experiments, this crosstalk can be cancelled by driving a small antiphase compensation signal on the Green channel.

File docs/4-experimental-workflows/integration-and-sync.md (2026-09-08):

# Integration & Multi-Modal Synchronization

Complex experiments often require synchronized acquisition across multiple data streams: visual stimulation timestamps, high-speed eye tracking, inertial motion measurements, and neural electrophysiology or imaging.

!!! note "Work in Progress"
    This documentation section is currently a work in progress.

---

## Synchronization Architecture

```mermaid
flowchart TD
    subgraph Hardware["⚡ Hardware TTL Signals"]
        direction LR
        MCU_P4["<b>Microcontroller Pin 4</b><br/><i>Indicator / Frame Toggle</i>"]
        MCU_P5["<b>Microcontroller Pin 5</b><br/><i>Stimulus Active Gate</i>"]
    end

    subgraph Software["💻 Software Acquisition (LabStreamingLayer)"]
        direction LR
        Bonsai["<b>Bonsai Stimulus Engine</b><br/><i>LSL Outlet: Stimulus Events</i>"]
        Neon["<b>Pupil Labs Neon Tracker</b><br/><i>LSL Outlet: Gaze and Video</i>"]
        IMU["<b>Motion / IMU Stream</b><br/><i>LSL Outlet: 6-DOF Kinematics</i>"]
    end

    SyncBox["<b>Hardware DAQ / Sync Box</b><br/><i>Open Ephys / Intan / NI-DAQ</i>"]
    LabRecorder["<b>LabRecorder Multi-Stream Host</b><br/><i>Synchronized XDF Output File</i>"]

    MCU_P4 --> SyncBox
    MCU_P5 --> SyncBox
    Bonsai --> LabRecorder
    Neon --> LabRecorder
    IMU --> LabRecorder
    SyncBox -.->|Hardware Clocks| LabRecorder
```

---

## 1. Hardware TTL Synchronization Pins

The microcontroller outputs real-time TTL state flags to synchronize external acquisition systems (e.g. Open Ephys, Intan, National Instruments DAQ):
* **Pin 4 (Indicator Toggle):** Inverts logic state on every stimulus update, frame transition, or trial onset.
* **Pin 5 (Stimulus Status):** Drives `HIGH` throughout the active stimulus duration and returns to `LOW` during inter-trial intervals (ITIs).

---

## 2. Pupil Labs Neon Eye Tracking Integration

* **Workflow:** [`BonsaiCode/streamNeonDev.bonsai`](file:///d:/Code/LEDStimulation/BonsaiCode/streamNeonDev.bonsai)
* **Description:** Connects to the Pupil Labs Neon mobile eye-tracking stream over network API / RTSP / LSL to record:
  * 200 Hz binocular eye camera video and pupil diameter.
  * Real-time gaze coordinates in pixel and visual angle coordinates.
  * Scene camera video synchronized with optical stimulation onset.

---
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

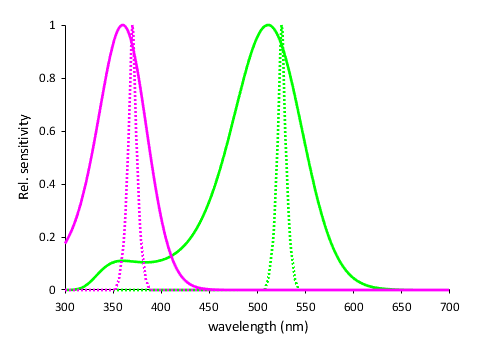
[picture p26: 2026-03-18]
Calibration/LEDdata/untitled.png

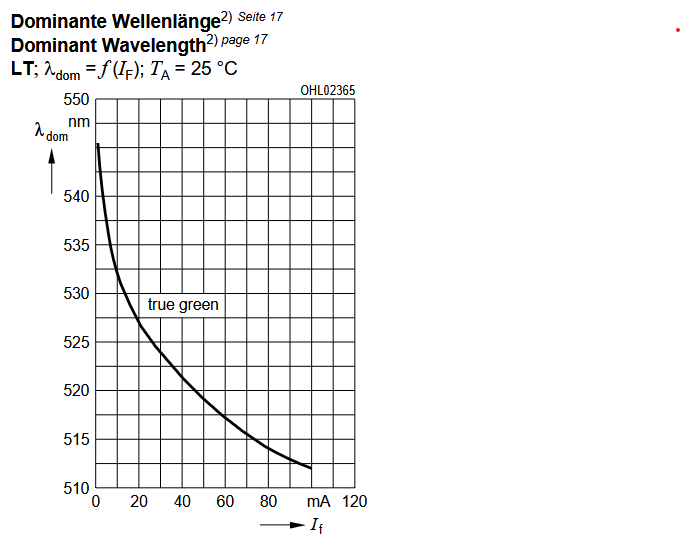
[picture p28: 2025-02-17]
Calibration/green_LED_DominantWavelength_x_current.png

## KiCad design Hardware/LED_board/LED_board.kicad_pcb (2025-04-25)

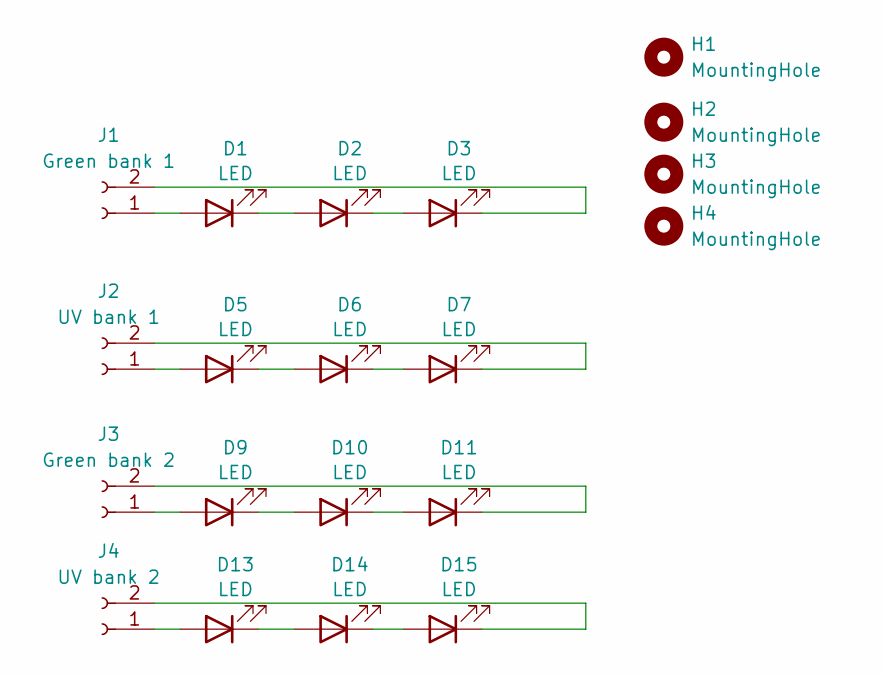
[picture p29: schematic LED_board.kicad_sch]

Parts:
D1, D2, D3, D9, D10, D11: LED; LED-SMD_L3.5-W2.8_RED
D5, D6, D7, D13, D14, D15: LED; LED-SMD_L3.5-W2.8-FD_WHITE-1
H1, H2, H3, H4: MountingHole; MountingHole_3.2mm_M3
J1: Green bank 1; PinSocket_1x02_P2.54mm_Horizontal
J2: UV bank 1; PinSocket_1x02_P2.54mm_Horizontal
J3: Green bank 2; PinSocket_1x02_P2.54mm_Horizontal
J4: UV bank 2; PinSocket_1x02_P2.54mm_Horizontal

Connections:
unnamed: D1.2 (A), J1.1
unnamed: D1.1 (K), D2.2 (A)
unnamed: D2.1 (K), D3.2 (A)
unnamed: D3.1 (K), J1.2
unnamed: D5.2 (A), J2.1
unnamed: D5.1 (K), D6.2 (A)
unnamed: D6.1 (K), D7.2 (A)
unnamed: D7.1 (K), J2.2
unnamed: D9.2 (A), J3.1
unnamed: D9.1 (K), D10.2 (A)
unnamed: D10.1 (K), D11.2 (A)
unnamed: D11.1 (K), J3.2
unnamed: D13.2 (A), J4.1
unnamed: D13.1 (K), D14.2 (A)
unnamed: D14.1 (K), D15.2 (A)
unnamed: D15.1 (K), J4.2

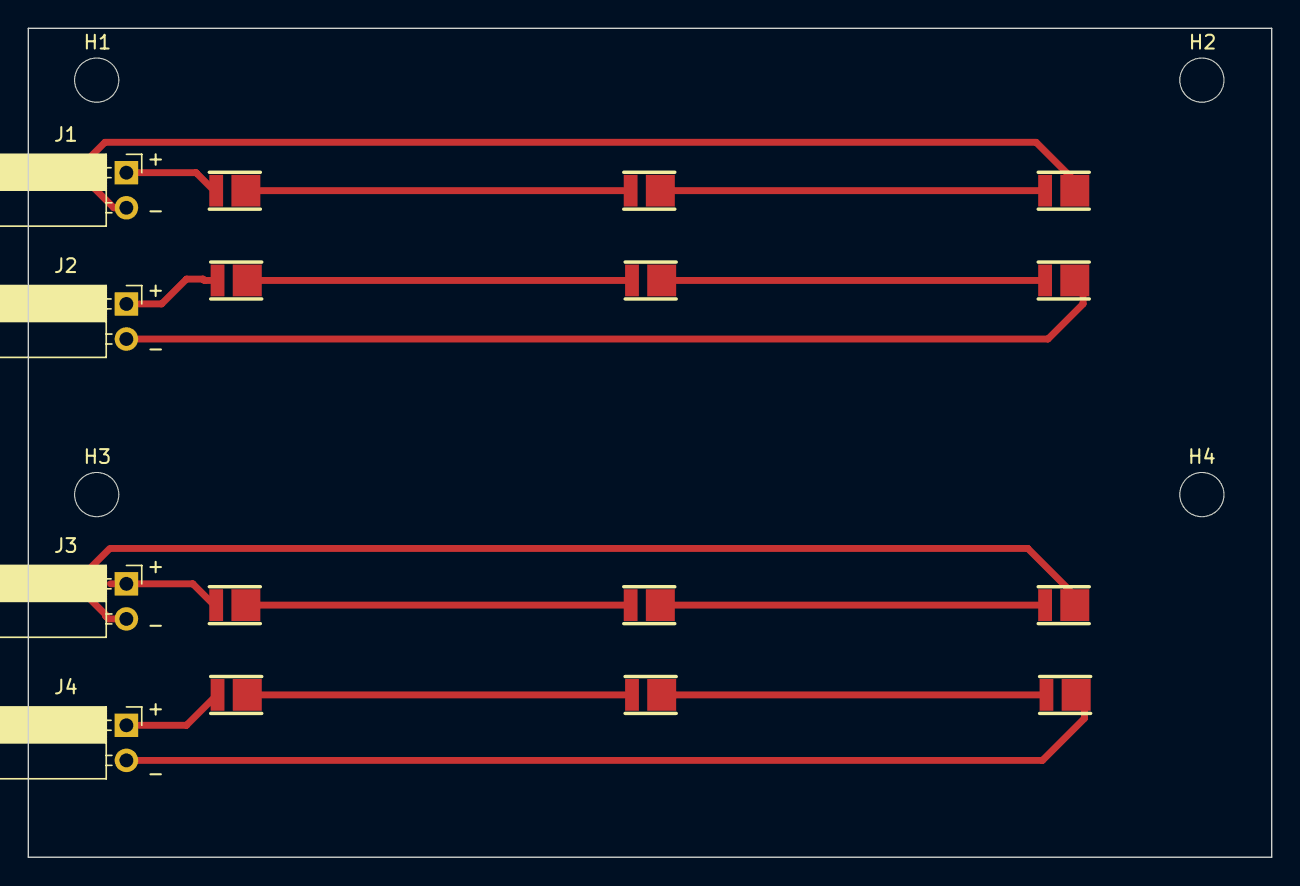
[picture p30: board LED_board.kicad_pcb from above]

Board: 2 copper layers, 90.0 x 60.0 mm, 20 parts (0 on the bottom side), 16 nets.

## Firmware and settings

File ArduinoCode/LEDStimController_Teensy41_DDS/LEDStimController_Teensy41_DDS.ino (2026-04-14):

// ==========================================================================
//  LEDStimController_Teensy41_DDS.ino
//
//  Teensy 4.1 DDS-based LED Stimulation Controller
//  Ported from Arduino Leonardo (ATmega32U4) version
//
//  PWM:  12-bit @ 36,621 Hz on pins 2 (ChA) and 3 (ChB)
//  DDS:  32-bit phase accumulator, 4096-entry sine LUT
//  ISR:  IntervalTimer (PIT) with NVIC priority 16
//
//  Serial Commands (carriage return terminated):
//    s,dur,fA,fB,phA,phB,conA,conB     - Sinewave flicker
//    se,dur,fA,fB,envF,conA,conB        - Sine with contrast envelope
//    fs,fmin,fmax,sweep,phA,phB,cA,cB   - Continuous frequency sweep
//    sfs,f0,f1,step,cyc,phA,phB,cA,cB   - Stepped frequency sweep
//    sd,dutyA,dutyB                      - Set static duty cycle (%)
//    sdt,dutyA,dutyB,durationMs          - Set duty cycle for duration
//    gc,step,wait,nReps                  - Cycle through duty cycles
//    useChA,0/1                          - Enable/disable channel A
//    useChB,0/1                          - Enable/disable channel B
//    agc,index                           - Select gamma LUT (1 or 2)
//    ana                                 - Read analog calibration voltages
//    bright,A/B,percent                  - Set brightness scale (0-100%)
//    loadlut,A/B,v0,v1,...,v4095         - Upload empirical gamma LUT
// ==========================================================================

#include <math.h>
#include <IntervalTimer.h>

// ========================== CONFIGURATION ==========================

#define PWM_PIN_A   2       // FlexPWM4, submodule 2, channel A
#define PWM_PIN_B   3       // FlexPWM4, submodule 2, channel B
#define PWM_FREQ    36621.09f  // 150 MHz / 4096 — exact 12-bit resolution
#define PWM_BITS    12
#define PWM_MAX     4095    // (1 << PWM_BITS) - 1

#define PIN_CYCLE_INDICATOR  4   // Toggles on carrier cycle completion
#define PIN_STIM_ON          5   // HIGH during stimulation

#define TABLE_SIZE  4096    // Sine wavetable entries (matches PWM resolution)
#define TARGET_RECONFIG_INTERVAL_US 1000L  // Frequency sweep update interval

// --- Fade & Envelope ---
#define FADE_DURATION_MS    50.0f    // Fade-in/out time in milliseconds (0 = disabled)
#define FADE_LUT_SIZE       64
#define FADE_LUT_MAX        (FADE_LUT_SIZE - 1)

// --- Fixed-point scale for 12-bit ---
#define FIXED_SCALE     4096
#define FIXED_SHIFT     12

// ========================== GAMMA LUTs ==========================
// Two hardcoded LUT slots — paste empirical calibration data here,
// or upload at runtime via serial "loadlut" command.

// LUT 1: Linear (identity mapping)
uint16_t gammaLUT1[PWM_MAX + 1];

// LUT 2: Placeholder for empirical data (initialised to linear)
uint16_t gammaLUT2[PWM_MAX + 1];

// Active gamma LUT pointers — volatile because the ISR reads them and the main loop writes them
uint16_t * volatile currentGammaLUT_A;
uint16_t * volatile currentGammaLUT_B;

// Post-LUT brightness scaling (0–4096 = 0%–100%)
volatile uint16_t brightnessScaleA = FIXED_SCALE;
volatile uint16_t brightnessScaleB = FIXED_SCALE;

// Last pre-gamma value written to each channel — used to immediately re-apply
// the output when brightness scale changes (e.g. from the bright,A,50 command)
volatile uint16_t lastPwmValA = 0;
volatile uint16_t lastPwmValB = 0;

// ========================== PWM VARIABLES ==========================

uint16_t maxBrightness;   // Artificial TOP for flexible brightness control
uint16_t midBrightness;   // maxBrightness / 2

float actualPWMFreq = PWM_FREQ;  // Hardware-accurate frequency for DDS calculations

// ========================== CHANNEL SELECTION ==========================

// volatile: written by main loop (serial command), read by ISR
volatile bool useChA = true;
volatile bool useChB = true;

// ========================== SERIAL ==========================

// numChars covers all normal commands. The longest (sfs, 9 params) is well under 50 chars.
// For loadlut, always use stream mode (send just "loadlut,A" then values separately);
// inline mode is limited to ~5-6 test values due to this 50-char buffer.
const byte numChars = 50;
char receivedChars[numChars];
bool newData = false;

// ========================== SINE WAVETABLE ==========================

uint16_t sineWaveTable[TABLE_SIZE];

// ========================== DDS VARIABLES ==========================

volatile uint32_t phaseAccumulatorA = 0;
volatile uint32_t phaseAccumulatorB = 0;
volatile uint32_t phaseIncrementA = 0;
volatile uint32_t phaseIncrementB = 0;

volatile uint32_t envAccumulator = 0;
volatile uint32_t envIncrement = 0;

volatile uint16_t contrastMultIntA = FIXED_SCALE;
volatile uint16_t contrastMultIntB = FIXED_SCALE;

// Tracks full sine wave cycles (for frequency sweeps)
volatile uint32_t completedCycles = 0;

// ========================== RAISED COSINE ENVELOPE ==========================

uint16_t raisedCosineLUT[FADE_LUT_SIZE];
volatile unsigned long currentTick = 0;         // Master clock (ISR tick counter)
volatile unsigned long fadeInterrupts = 0;
volatile unsigned long fadeOutStartInterrupt = 0;
volatile uint32_t envStep = 0;

// ========================== INTERVAL TIMER ==========================

IntervalTimer ddsTimer;

// ========================== DDS PHASE INCREMENT ==========================

// Pre-computed scale factor: 2^32 / actualPWMFreq
// 2^32 = 4294967296 — the full range of the 32-bit phase accumulator.
// One full sine cycle (0 to 2π) maps onto the full 0 to 2^32 range.
// When the accumulator overflows past 2^32, it wraps — giving continuous oscillation.
static float phaseScale;

uint32_t calcPhaseInc(float freq) {
  return (uint32_t)(freq * phaseScale);
}

// ========================== PWM OUTPUT ==========================

// Apply gamma correction + post-LUT brightness scaling, then write to PWM.
// NOTE: analogWrite() is called from ISR context (sinewaveInterrupt etc.).
// On Teensy 4.1 this works reliably at 36.6 kHz — the function is fast and
// the FlexPWM double-buffer ensures glitch-free updates. If issues arise,
// replace with direct IMXRT_FLEXPWM4.SM[2].VAL3 / VAL5 register writes.
inline void setChA(uint16_t value) {
  lastPwmValA = value;  // Track for immediate re-apply on brightness change
  uint16_t gammaVal = currentGammaLUT_A[value];
  uint16_t scaled = ((uint32_t)gammaVal * brightnessScaleA) >> FIXED_SHIFT;
  analogWrite(PWM_PIN_A, scaled);
}

inline void setChB(uint16_t value) {
  lastPwmValB = value;  // Track for immediate re-apply on brightness change
  uint16_t gammaVal = currentGammaLUT_B[value];
  uint16_t scaled = ((uint32_t)gammaVal * brightnessScaleB) >> FIXED_SHIFT;
  analogWrite(PWM_PIN_B, scaled);
}

// ========================== SETUP ==========================

void setup() {
  // --- PWM Pins ---
  pinMode(PWM_PIN_A, OUTPUT);
  pinMode(PWM_PIN_B, OUTPUT);
  analogWriteFrequency(PWM_PIN_A, PWM_FREQ);  // Sets both pins (same FlexPWM submodule)
  analogWriteResolution(PWM_BITS);

  // --- Indicator Pins ---
  pinMode(PIN_CYCLE_INDICATOR, OUTPUT);
  pinMode(PIN_STIM_ON, OUTPUT);
  digitalWriteFast(PIN_CYCLE_INDICATOR, LOW);
  digitalWriteFast(PIN_STIM_ON, LOW);

  // --- Serial ---
  Serial.begin(115200);

  // --- Compute DDS phase scale factor ---
  phaseScale = 4294967296.0f / actualPWMFreq;

  // --- Generate linear gamma LUTs (default) ---
  generateLinearGammaLUT(gammaLUT1, PWM_MAX);
  generateLinearGammaLUT(gammaLUT2, PWM_MAX);
  currentGammaLUT_A = gammaLUT1;
  currentGammaLUT_B = gammaLUT1;

  // --- Generate raised cosine envelope LUT (0 to FIXED_SCALE) ---
  for (int i = 0; i < FADE_LUT_SIZE; i++) {
    float angle = PI * (float)i / (float)FADE_LUT_MAX;
    float val = (1.0f - cosf(angle)) / 2.0f;
    raisedCosineLUT[i] = (uint16_t)(val * (float)FIXED_SCALE);
    if (raisedCosineLUT[i] > FIXED_SCALE) raisedCosineLUT[i] = FIXED_SCALE;
  }

  // --- Set brightness range ---
  maxBrightness = PWM_MAX;
  midBrightness = PWM_MAX / 2;

  // --- Generate sine wave LUT ---
  generateSineWaveTable(maxBrightness);

  // --- Set default 50% duty cycle ---
  if (useChA) { setChA(midBrightness); }
  if (useChB) { setChB(midBrightness); }
}

// ========================== MAIN LOOP ==========================

void loop() {
  GetSerialInput();
  if (newData) {
    newData = false;
    ActionSerial();
  }
}

// ========================== SERIAL INPUT ==========================

void GetSerialInput() {
  static byte ndx = 0;
  char endMarker = '\r';
  char rc;
  if (Serial.available() > 0) {
    rc = Serial.read();
    if (rc != endMarker) {
      receivedChars[ndx] = rc;
      ndx++;
      if (ndx >= numChars) {
        ndx = numChars - 1;
      }
    } else {
      receivedChars[ndx] = '\0';
      ndx = 0;
      newData = true;
    }
  }
}

// ========================== SERIAL COMMAND DISPATCH ==========================

void ActionSerial() {
  Serial.print(F("rc: "));
  Serial.print(receivedChars);
  Serial.print(F("\n"));

  char *token;
  uint8_t idx = 0;
#define MAX_VALS 50
  char *serialVals[MAX_VALS];
  token = strtok(receivedChars, ",");

  while (token != NULL) {
    if (idx < MAX_VALS)
      serialVals[idx++] = token;
    token = strtok(NULL, ",");
  }

  // Guard: if no tokens were parsed (empty/whitespace-only command), do nothing
  if (idx == 0) {
    memset(receivedChars, '\0', sizeof(receivedChars));
    return;
  }

  char *FirstChar = serialVals[0];

  // s, durationMs, freqA, freqB, phaseA, phaseB, contrastA, contrastB  [8 tokens]
  if (strcmp(FirstChar, "s") == 0)
  {
    if (idx < 8) { Serial.print(F("ERR: s needs 7 params\n")); return; }
    long stimulusDuration = atof(serialVals[1]);
    float freqA = atof(serialVals[2]);
    float freqB = atof(serialVals[3]);
    float phaseA = atof(serialVals[4]);
    float phaseB = atof(serialVals[5]);
    float contrastA = atof(serialVals[6]);
    float contrastB = atof(serialVals[7]);

    outputSinewave(freqA, freqB, stimulusDuration, phaseA, phaseB, contrastA, contrastB);
  }
  // se, durationMs, freqA, freqB, envFreq, maxContrastA, maxContrastB  [7 tokens]
  else if (strcmp(FirstChar, "se") == 0)
  {
    if (idx < 7) { Serial.print(F("ERR: se needs 6 params\n")); return; }
    long stimulusDuration = atof(serialVals[1]);
    float freqA = atof(serialVals[2]);
    float freqB = atof(serialVals[3]);
    float envFrequency = atof(serialVals[4]);
    float maxContrastA = atof(serialVals[5]);
    float maxContrastB = atof(serialVals[6]);

    SineContrastConv(stimulusDuration, freqA, freqB, envFrequency, maxContrastA, maxContrastB);
  }
  // fs, fmin, fmax, sweep, phA, phB, cA, cB  [8 tokens]
  else if (strcmp(FirstChar, "fs") == 0)
  {
    if (idx < 8) { Serial.print(F("ERR: fs needs 7 params\n")); return; }
    float fmin = atof(serialVals[1]);
    float fmax = atof(serialVals[2]);
    float sweepFactorPerSec = atof(serialVals[3]);
    float phaseA = atof(serialVals[4]);
    float phaseB = atof(serialVals[5]);
    float contrastA = atof(serialVals[6]);
    float contrastB = atof(serialVals[7]);

    FrequencySweep(fmin, fmax, sweepFactorPerSec,
                   phaseA, phaseB, contrastA, contrastB);
  }
  // sfs, f0, f1, step, cyc, phA, phB, cA, cB  [9 tokens]
  else if (strcmp(FirstChar, "sfs") == 0)
  {
    if (idx < 9) { Serial.print(F("ERR: sfs needs 8 params\n")); return; }
    float startFreq = atof(serialVals[1]);
    float endFreq = atof(serialVals[2]);
    float stepFreq = atof(serialVals[3]);
    int cyclesPerFreq = atoi(serialVals[4]);
    float phaseA = atof(serialVals[5]);
    float phaseB = atof(serialVals[6]);
    float contrastA = atof(serialVals[7]);
    float contrastB = atof(serialVals[8]);

    SteppedFrequencySweep(startFreq, endFreq, stepFreq, cyclesPerFreq, phaseA, phaseB, contrastA, contrastB);
  }
  // sd, dutyA, dutyB  [3 tokens]
  else if (strcmp(FirstChar, "sd") == 0)
  {
    if (idx < 3) { Serial.print(F("ERR: sd needs 2 params\n")); return; }
    float dutyCycle_A = atof(serialVals[1]);
    float dutyCycle_B = atof(serialVals[2]);
    setDutyCycle(dutyCycle_A, dutyCycle_B);
  }
  // sdt, dutyA, dutyB, durationMs  [4 tokens]
  else if (strcmp(FirstChar, "sdt") == 0)
  {
    if (idx < 4) { Serial.print(F("ERR: sdt needs 3 params\n")); return; }
    float dutyCycle_A = atof(serialVals[1]);
    float dutyCycle_B = atof(serialVals[2]);
    long stimulusDuration = atof(serialVals[3]);

    setDutyCycleTime(dutyCycle_A, dutyCycle_B, stimulusDuration);
  }
  // gc, step, wait, nReps  [4 tokens]
  else if (strcmp(FirstChar, "gc") == 0)
  {
    if (idx < 4) { Serial.print(F("ERR: gc needs 3 params\n")); return; }
    float stepSize = atof(serialVals[1]);
    long waitTime = atof(serialVals[2]);
    int nReps = atof(serialVals[3]);
    cycleDutyCycles(stepSize, waitTime, nReps);
  }
  else if (strcmp(FirstChar, "useChB") == 0)
  {
    useChB = atoi(serialVals[1]);
    if (!useChB) {
      Serial.print(F("ChB OFF\n"));
    } else {
      Serial.print(F("ChB ON\n"));
    }
  }
  else if (strcmp(FirstChar, "useChA") == 0)
  {
    useChA = atoi(serialVals[1]);
    if (!useChA) {
      Serial.print(F("ChA OFF\n"));
    } else {
      Serial.print(F("ChA ON\n"));
    }
  }
  else if (strcmp(FirstChar, "ana") == 0) {
    readAnalogVals();
  }
  else if (strcmp(FirstChar, "agc") == 0)
  {
    uint8_t lutIndex = atoi(serialVals[1]);
    if (lutIndex == 1) {
      currentGammaLUT_A = gammaLUT1;
      currentGammaLUT_B = gammaLUT1;
      Serial.print(F("LUT 1 SELECTED\n"));
    } else if (lutIndex == 2) {
      currentGammaLUT_A = gammaLUT2;
      currentGammaLUT_B = gammaLUT2;
      Serial.print(F("LUT 2 SELECTED\n"));
    }
  }
  // bright,A/B,percent  — immediately rescales current PWM output
  else if (strcmp(FirstChar, "bright") == 0)
  {
    if (idx < 3) { Serial.print(F("ERR: bright needs 2 params\n")); return; }
    char *channel = serialVals[1];
    float percent = atof(serialVals[2]);
    if (percent < 0.0f) percent = 0.0f;
    if (percent > 100.0f) percent = 100.0f;
    uint16_t scale = (uint16_t)(percent / 100.0f * FIXED_SCALE);

    if (strcmp(channel, "A") == 0 || strcmp(channel, "a") == 0) {
      brightnessScaleA = scale;
      setChA(lastPwmValA);  // Immediately re-apply current output at new brightness
      Serial.print(F("ChA brightness: "));
    } else {
      brightnessScaleB = scale;
      setChB(lastPwmValB);  // Immediately re-apply current output at new brightness
      Serial.print(F("ChB brightness: "));
    }
    Serial.print(percent);
    Serial.print(F("%\n"));
  }
  // --- NEW: Upload empirical gamma LUT via ASCII ---
  // loadlut,A,v0,v1,v2,...,v4095
  else if (strcmp(FirstChar, "loadlut") == 0)
  {
    // Loads empirical gamma LUT data into gammaLUT1 (channel A) or gammaLUT2 (channel B).
    // Always writes into the named backing array, not into wherever the pointer currently
    // points — so the active LUT is only updated once loading is complete.
    //
    // Usage:
    //   "loadlut,A"              → stream mode: send comma-separated values then "END"
    //   "loadlut,B"              → same for channel B
    //   "loadlut,A,0,1,3,7,..."  → inline mode (max ~40 values due to 50-char buffer;
    //                              use stream mode for the full 4096-entry LUT)
    char *channel = serialVals[1];
    bool isChA = (strcmp(channel, "A") == 0 || strcmp(channel, "a") == 0);
    uint16_t *targetLUT = isChA ? gammaLUT1 : gammaLUT2;

    if (idx > 2) {
      // Inline mode — limited by numChars buffer, useful for small test LUTs
      int count = idx - 2;
      if (count > PWM_MAX + 1) count = PWM_MAX + 1;
      for (int i = 0; i < count; i++) {
        targetLUT[i] = (uint16_t)atoi(serialVals[i + 2]);
      }
      // Switch active pointer to the newly written slot
      if (isChA) { currentGammaLUT_A = targetLUT; }
      else        { currentGammaLUT_B = targetLUT; }
      Serial.print(F("LUT loaded: "));
      Serial.print(count);
      Serial.print(F(" values\n"));
    } else {
      // Stream mode: read 4096 comma-separated values then "END"
      Serial.print(F("SEND_LUT_DATA\n"));
      loadLUTFromSerial(targetLUT);
      // Switch active pointer only after successful load
      if (isChA) { currentGammaLUT_A = targetLUT; }
      else        { currentGammaLUT_B = targetLUT; }
    }
  }
  else
  {
    Serial.print(FirstChar);
    Serial.print(F(" is an invalid stimulus code - make sure you are using carriage return line ending\n"));
  }
  memset(receivedChars, '\0', sizeof(receivedChars));
}

// ========================== LUT UPLOAD (STREAM MODE) ==========================
// Reads 4096 comma-separated values from serial, split across multiple lines.
// Send values separated by commas, terminated with a line containing "END".

void loadLUTFromSerial(uint16_t *targetLUT) {
  int loaded = 0;
  char buf[64];
  int bufIdx = 0;
  unsigned long lastRxTime = millis();  // Timeout tracker

  while (loaded < PWM_MAX + 1) {

    // Escape hatch: if no data arrives within 5 seconds, abort
    if (millis() - lastRxTime > 5000) {
      Serial.print(F("LUT_LOAD_ERROR: TIMEOUT after "));
      Serial.print(loaded);
      Serial.print(F(" values\n"));
      return;  // Leaves targetLUT partially written; caller will not update the active pointer
    }

    if (Serial.available() > 0) {
      lastRxTime = millis();  // Reset timeout on every received byte
      char c = Serial.read();

      if (c == ',' || c == '\r' || c == '\n') {
        if (bufIdx > 0) {
          buf[bufIdx] = '\0';

          // Check for END marker
          if (strcmp(buf, "END") == 0 || strcmp(buf, "end") == 0) {
            break;
          }

          targetLUT[loaded] = (uint16_t)atoi(buf);
          loaded++;
          bufIdx = 0;
        }
      } else if (bufIdx < 63) {
        buf[bufIdx++] = c;
      }
    }
  }

  Serial.print(F("LUT_LOADED: "));
  Serial.print(loaded);
  Serial.print(F(" values\n"));
}

// ========================== GAMMA LUT GENERATION ==========================

void generateLinearGammaLUT(uint16_t *lut, uint16_t maxOutput) {
  for (int i = 0; i <= PWM_MAX; i++) {
    lut[i] = (uint16_t)((uint32_t)i * maxOutput / PWM_MAX);
  }
}

void generateGammaLUT(uint16_t *lut, float gamma, uint16_t maxOutput) {
  for (int i = 0; i <= PWM_MAX; i++) {
    float normalized = (float)i / (float)PWM_MAX;
    float corrected = powf(normalized, gamma);
    lut[i] = (uint16_t)(corrected * maxOutput + 0.5f);
  }
}

// ========================== SINE WAVETABLE GENERATION ==========================

void generateSineWaveTable(uint16_t top) {
  for (int i = 0; i < TABLE_SIZE; i++) {
    float angle = (2.0f * PI * i) / TABLE_SIZE;
    // +0.5f for rounding to nearest integer instead of truncating
    sineWaveTable[i] = (uint16_t)(((sinf(angle) + 1.0f) * (top / 2.0f)) + 0.5f);
  }
}

// ========================== SINEWAVE FLICKER (DDS) ==========================

void outputSinewave(float freqA, float freqB, long duration, float phaseA, float phaseB, float contrastA, float contrastB) {

  // Phase: 0.0 = 0°, 0.25 = 90°, 0.5 = 180°, etc.
  phaseAccumulatorA = (uint32_t)(phaseA * 4294967296.0f);
  phaseAccumulatorB = (uint32_t)(phaseB * 4294967296.0f);

  contrastMultIntA = (uint16_t)(contrastA * (float)FIXED_SCALE);
  contrastMultIntB = (uint16_t)(contrastB * (float)FIXED_SCALE);

  phaseIncrementA = calcPhaseInc(freqA);
  phaseIncrementB = calcPhaseInc(freqB);

  // --- Temporal window & master clock setup ---
  unsigned long totalInterrupts = (unsigned long)((duration / 1000.0f) * actualPWMFreq);

  float fadeTimeMs = FADE_DURATION_MS;

  if (fadeTimeMs > 0.0f) {
    fadeInterrupts = (unsigned long)(actualPWMFreq * (fadeTimeMs / 1000.0f));
    if (fadeInterrupts > totalInterrupts / 2) {
      fadeInterrupts = totalInterrupts / 2;
    }
    fadeOutStartInterrupt = totalInterrupts - fadeInterrupts;

    // Mathematically forces division to round UP
    envStep = (((uint32_t)FADE_LUT_MAX << 16) + fadeInterrupts - 1) / fadeInterrupts;
  } else {
    fadeInterrupts = 0;
    fadeOutStartInterrupt = 4294967295UL;
    envStep = 0;
  }

  currentTick = 0;
  completedCycles = 0;

  if (useChA) { setChA(midBrightness); }
  if (useChB) { setChB(midBrightness); }

  digitalWriteFast(PIN_STIM_ON, HIGH);
  digitalWriteFast(PIN_CYCLE_INDICATOR, HIGH);

  startDDS(sinewaveInterrupt);

  // Wait for the master clock to reach total duration
  unsigned long safeTick = 0;
  while (true) {
    noInterrupts();
    safeTick = currentTick;
    interrupts();

    if (safeTick >= totalInterrupts) break;

    delayMicroseconds(1);
  }

  stopDDS();

  digitalWriteFast(PIN_CYCLE_INDICATOR, LOW);
  digitalWriteFast(PIN_STIM_ON, LOW);
  Serial.print(F("-1\n"));

  if (useChA) { setChA(midBrightness); }
  if (useChB) { setChB(midBrightness); }
}
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

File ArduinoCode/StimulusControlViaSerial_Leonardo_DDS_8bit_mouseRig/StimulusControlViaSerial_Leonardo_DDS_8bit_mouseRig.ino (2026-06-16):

#include <math.h>  

#define CLOCK_FREQ 16000000                // Arduino Leonardo clock frequency (16 MHz)
#define TABLE_SIZE 256                     // Number of samples in the wavetable
#define TARGET_RECONFIG_INTERVAL_US 1000L  // FOR FREQUENCY SWEEP 1000 microseconds = 1 millisecond

// --- FADE & ENVELOPE MACROS ---
#define FADE_DURATION_MS 100.0             // Easily change the fade-in/out time in milliseconds here!
#define FADE_LUT_SIZE 64                   // Change this to 64, 128, 256, 512, etc.
#define FADE_LUT_MAX (FADE_LUT_SIZE - 1)   // Used for safe zero-indexed math

// --- OPTIMIZATION: 8-Bit PROGMEM Arrays ---
const uint8_t PROGMEM ChA1LUT[256] = {
  0, 4, 6, 8, 9, 11, 12, 13, 15, 16, 17, 18, 19, 20, 21, 23, 
  24, 25, 26, 27, 28, 29, 30, 31, 32, 34, 35, 36, 37, 38, 39, 40, 
  41, 42, 43, 44, 45, 46, 47, 48, 50, 51, 52, 53, 54, 55, 56, 57, 
  58, 59, 60, 61, 62, 63, 64, 65, 67, 68, 69, 70, 71, 72, 73, 74, 
  75, 76, 77, 78, 79, 80, 81, 82, 83, 84, 85, 86, 87, 88, 89, 90, 
  91, 92, 93, 94, 95, 96, 97, 98, 99, 100, 101, 102, 103, 105, 105, 106, 
  107, 108, 109, 110, 111, 112, 113, 114, 115, 116, 117, 118, 119, 120, 121, 122, 
  123, 124, 125, 126, 127, 128, 129, 130, 131, 132, 133, 134, 135, 136, 137, 138, 
  139, 139, 140, 141, 142, 143, 144, 145, 146, 147, 148, 149, 150, 151, 152, 153, 
  154, 155, 156, 156, 157, 158, 159, 160, 161, 162, 163, 164, 165, 166, 167, 168, 
  168, 169, 170, 171, 172, 173, 174, 175, 176, 177, 178, 179, 180, 181, 182, 182, 
  183, 184, 185, 186, 187, 188, 189, 190, 191, 191, 192, 193, 194, 195, 196, 197, 
  198, 199, 200, 201, 202, 202, 203, 204, 205, 206, 207, 208, 209, 209, 210, 211, 
  212, 213, 214, 215, 216, 216, 217, 218, 219, 220, 221, 222, 222, 223, 224, 225, 
  226, 227, 228, 228, 229, 230, 231, 232, 233, 234, 234, 235, 236, 237, 238, 239, 
  240, 241, 241, 242, 243, 244, 245, 246, 246, 247, 248, 249, 250, 251, 252, 253
};

const uint8_t PROGMEM ChB1LUT[256] = {
  0, 4, 6, 7, 8, 10, 11, 12, 13, 15, 16, 17, 18, 19, 20, 22, 
  23, 24, 25, 26, 28, 29, 30, 31, 32, 34, 35, 36, 37, 38, 40, 41, 
  42, 43, 44, 45, 47, 48, 49, 50, 51, 52, 54, 55, 56, 57, 58, 59, 
  60, 62, 62, 64, 65, 66, 67, 68, 69, 70, 72, 73, 74, 75, 76, 77, 
  78, 80, 81, 82, 83, 84, 85, 86, 87, 88, 89, 91, 92, 93, 94, 95, 
  96, 97, 98, 99, 100, 101, 102, 104, 105, 106, 107, 108, 109, 110, 111, 112, 
  113, 114, 115, 116, 117, 118, 119, 120, 121, 122, 123, 124, 125, 126, 127, 128, 
  129, 130, 131, 132, 133, 134, 135, 136, 137, 138, 139, 140, 141, 142, 143, 144, 
  145, 146, 147, 148, 149, 150, 151, 151, 152, 153, 154, 155, 156, 157, 158, 159, 
  160, 161, 162, 163, 164, 164, 165, 166, 167, 168, 169, 170, 171, 171, 172, 173, 
  174, 175, 176, 177, 178, 179, 180, 181, 181, 182, 183, 184, 185, 186, 187, 188, 
  188, 189, 190, 191, 192, 193, 194, 195, 196, 197, 198, 199, 200, 200, 201, 202, 
  203, 204, 204, 205, 206, 207, 208, 209, 210, 210, 211, 212, 213, 214, 215, 215, 
  216, 217, 218, 219, 220, 221, 222, 222, 223, 224, 225, 226, 226, 227, 228, 229, 
  230, 230, 231, 232, 233, 234, 234, 235, 236, 237, 237, 238, 239, 240, 240, 241, 
  242, 242, 243, 244, 244, 245, 246, 246, 247, 248, 249, 249, 250, 251, 252, 253
};

const uint8_t *currentChALUT;
const uint8_t *currentChBLUT;

// PWM variables
long prescaler;
uint16_t TOP;  
long TopLumi;  
long MidLumi;

// 31.25 kHz target to kill saccadic CFF artifacts
long desiredPWMFrequency = 31250;  
float actualPWMFreq = 31249.2;     // Hardware-accurate frequency for DDS calculations

// channel selection
bool useChA = true;
bool useChB = true;

// serial
const byte numChars = 50;
char receivedChars[numChars];  
bool newData = false;

// Array to hold the wavetable
uint16_t sineWaveTable[TABLE_SIZE];

// --- DDS (Direct Digital Synthesis) Variables ---
volatile uint32_t phaseAccumulatorA = 0;
volatile uint32_t phaseAccumulatorB = 0;
volatile uint32_t phaseIncrementA = 0;
volatile uint32_t phaseIncrementB = 0;

volatile uint32_t envAccumulator = 0;
volatile uint32_t envIncrement = 0;

volatile uint16_t contrastMultIntA = 255; // Default scaled to 255 Max
volatile uint16_t contrastMultIntB = 255;

// Tracks full sine wave cycles safely up to 4.2 billion
volatile uint32_t completedCycles = 0; 

// --- Raised Cosine Temporal Window Variables ---
uint8_t raisedCosineLUT[FADE_LUT_SIZE]; // 8-bit array saves memory and fetches faster
volatile unsigned long currentTick = 0; // The ultimate Master Clock
volatile unsigned long fadeInterrupts = 0;
volatile unsigned long fadeOutStartInterrupt = 0;
volatile uint32_t envStep = 0; 

// OPTIMIZATION: 32-bit addition accumulator to replace heavy multiplication in ISR
volatile uint32_t fadePhase = 0; 

// --- ATOMIC FLAG FIX FOR ISR STARVATION AND USB BLOCKING ---
volatile bool stimulusActive = false; 
volatile unsigned long targetTotalInterrupts = 0; 

// Function to calculate exact DDS phase increment 
uint32_t calcPhaseInc(float freq) {
  // 4294967296.0 / 31250.0 = 137438.953125
  // This executes instantly and is mathematically exact in IEEE 754.
  return (uint32_t)(freq * 137438.953125f + 0.5f);
}

void setup() {
  pinMode(9, OUTPUT);   // Pin 9 controlled by Timer1 (Channel A)
  pinMode(10, OUTPUT);  // Pin 10 controlled by Timer1 (Channel B)

  pinMode(4, OUTPUT);  // Pin 4 indicator pin
  pinMode(5, OUTPUT);  // Pin 5 stim ON or OFF pin

  PORTD &= ~(1 << PIND4);   
  PORTC &= ~(1 << PORTC6);  

  Serial.begin(115200);

  currentChALUT = ChA1LUT;
  currentChBLUT = ChB1LUT;

  // Generate the Modular Raised Cosine Envelope LUT (0 to 255 scale)
  for (int i = 0; i < FADE_LUT_SIZE; i++) {
    float angle = PI * (float)i / (float)FADE_LUT_MAX;         
    float val = (1.0 - cos(angle)) / 2.0;        
    raisedCosineLUT[i] = (uint8_t)(val * 255.0); // Maximum set to 255!
    if (raisedCosineLUT[i] > 255) raisedCosineLUT[i] = 255; 
  }

  // Calculate the prescaler and TOP value
  TOP = calculatePrescalerAndTOP(desiredPWMFrequency, prescaler);

  // Store the exact mathematical frequency the hardware actually achieved for DDS math
  actualPWMFreq = (float)CLOCK_FREQ / (2.0 * (float)prescaler * (float)TOP);

  // Apply the prescaler and TOP value to Timer1
  configureTimer1(prescaler, TOP);

  TopLumi = TOP;  
  MidLumi = TOP / 2;

  // Generate the sine wave LUT
  generateSineWaveTable(TopLumi);

  if (useChA) { setChA(TopLumi / 2); }  
  if (useChB) { setChB(TopLumi / 2); }  
}

void loop() {
  GetSerialInput();
  if (newData) {
    newData = false;
    ActionSerial();
  }
}

//////////////////////////////////////// HANDLE SERIAL INPUT //////////////////////////////////////
void GetSerialInput() {  
  static byte ndx = 0;
  char endMarker = '\r';
  char rc;
  if (Serial.available() > 0) {
    rc = Serial.read();
    if (rc != endMarker) {
      receivedChars[ndx] = rc;
      ndx++;
      if (ndx >= numChars) {
        ndx = numChars - 1;
      }
    } else {                      
      receivedChars[ndx] = '\0';  
      ndx = 0;
      newData = true;
    }
  }
}
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

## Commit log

2024-12-03 porting from MatrixRigs repo
    [ContrastSwitchingStimuliCSV.csv, FlickerSweepCSV.csv, GanzPDtest.csv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]
2024-12-05 fixed flicker stimulation workflow
    loading next stimulus + csv
    [flickerFreqCSV.csv, flickerFreqCSV_TEST.csv]
2024-12-05 Sinewave with contrat envelope workflow
    [sineEnvelopeCSV.csv]
2024-12-12 Update StimulusControlViaSerial_Leonardo_v2.ino
    removed 5s 0 lumiannce delay from white noise, this can be set manually now
    [StimulusControlViaSerial_Leonardo_v2.ino]
2024-12-19 changed pin 4 toggle as temp fix for table_index not always going to 0
    [ContrastSwitchingStimuliCSV.csv, FlickerSweepCSV.csv, GanzPDtest.csv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]
2025-02-07 fixed sinewave interrupts so that the table_index always starts at 0
    [StimulusControlViaSerial_Leonardo_v2.ino]
2025-02-13 Update StimulusControlViaSerial_Leonardo_v2.ino
    added gamma correction stimulus routine
    [StimulusControlViaSerial_Leonardo_v2.ino]
2025-02-17 calibration workflow for stimulator
    [S120VC_Responsivity.xlsx]
2025-02-19 update to calibrations
    [DATA01.CSV, DATA02.CSV, DATA03.CSV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]
2025-02-21 wip gamma correction
    [DATA01.CSV, DATA02.CSV, DATA03.CSV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]
2025-02-24 working on gamma correction
    [StimulusControlViaSerial_Leonardo_v2.ino]
2025-02-24 green120mA gc lut
    [green120mA.CSV]
2025-02-26 setup workflows for sussex
    [flickerFreqEnvelopeTrialsCSV.csv, flickerFreqTrialsCSV_sussex.csv, sineEnvelopeCSV_sussex.csv]
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2025-02-28 2-channel PWM signal
    Split green and UV to diff PWM channels (9 and 10), both on Timer1.
    Bool flags set over serial controls whether each channel is to be set on/off at any time
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2025-04-12 reorganise dirs
    [ContrastSwitchingStimuliCSV.csv, FlickerSweepCSV.csv, LED_board.kicad_pcb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]
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2025-04-15 added some hardware
    [Baseplate_for_PCBs.ipt, Constant_current_driver.kicad_pcb, Constant_current_driver.kicad_sch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]
2025-04-16 update hardware
    [Baseplate_for_PCBs.ipt, Baseplate_for_PCBs_mirroredHole.stp, Baseplate_for_PCBs_mirroredHoles.0001.ipt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]
2025-04-29 gaussian white noise sequences
    [DoubleGaussianWhiteNoise.ino, GaussianWhiteNoiseTest.ino, StimulusControlViaSerial_Leonardo_v5.ino]
2025-05-01 gaussian white noise update
    Updated code for white noise stimuli.
    1) now uses gaussian white noise, where random values are approx. gaussian using CLT
    2) fractional mean and std of TopLumi are additional input args
    3) if useChA and useChB, independent gaussian white noise sequences will be used
    [StimulusControlViaSerial_Leonardo_v5.ino]
2025-05-02 Update StimulusControlViaSerial_Leonardo_v5.ino
    "useChA/B" now means that current ocr values wont be updated during main stimulus functions, but can still be set by setDutyCycle.
    No longer defaults to turning off led either, but maintains current value.
    [StimulusControlViaSerial_Leonardo_v5.ino]
2025-05-16 Ported matrix rigs local bonsai and basic workflow
    [dists_sinewave_tfTuning.csv, stimuli_sinewave_tfTuning.csv]
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2025-05-20 Revert "reorganise dirs"
    This reverts commit e67b3b7d989c3398e2d401127244eebda8839525.
    [ContrastSwitchingStimuliCSV.csv, FlickerSweepCSV.csv, WhiteNoiseRFCSV.csv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]
2025-05-20 Revert "added flicker sweep functionality"
    This reverts commit 4845784872e3e7352c07020bf213f54e47fcadcb.
    [StimulusControlViaSerial_Leonardo_v6.ino, StimulusControlViaSerial_Leonardo_v7.ino]
2025-05-20 Create StimulusControlViaSerial_Leonardo_v7.ino
    frequency sweep and frozen white noise stim
    [StimulusControlViaSerial_Leonardo_v7.ino]
2025-05-21 calibration of new setup init
    [DATA01.CSV, DATA02.CSV, DATA03.CSV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]
2025-05-21 updating indicator pin behaviour (see issues)
    [StimulusControlViaSerial_Leonardo_v7.ino]
2025-05-21 some indicator pin updates and new bonsai workflow specification style
    [dists_OnOff_fullContrast.csv, dists_sinewave_tfTuning.csv, stimuli_OnOff_fullContrast.csv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]
2025-05-22 updating calibration code to work with PDA100A2 pd
    [PDA100A2_responsivity.xlsx, S120C_Responsivity.xlsx]
2025-05-22 Gamma correction
    including to dynamically select the required LUT
    [UV102.CSV, UV103.CSV, green102.CSV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]
2025-05-23 corrected types in arduino code
    [green102_wCorr.CSV, green103_wCorr.CSV]
2025-05-28 updates pre first recording
    [dists_chirp.csv, dists_sinewave_contrastTuning.csv, dists_wnTest.csv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]
2025-05-30 spec files for chromatic stim
    [dists_balancedStepChanges.csv, stimuli_balancedStepChanges.csv]
2025-05-30 some stimulus spec files and updating white noise generaiton
    [dists_balancedSineWaves.csv, dists_fwn30mins.csv, dists_wn30mins.csv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]
2025-06-02 testing new white noise generation + added timestamp to arduino PWM data in bonsai
2025-06-03 organise stimulus spec csv files
    [dists_OnOff_fullContrast.csv, dists_balancedSineWaves.csv, dists_balancedStepChanges.csv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]
2025-06-03 replaced serial.println withn Serial.print("\n")
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2025-06-09 high rep sinewaves spec file
    [dists_sinewave_contrastTuning.csv, stimuli_sinewave_highreps.csv]
2025-06-18 reorgansie stimulus spec files
    [dists_contrastSwitching.csv, dists_meanSwitching.csv, stimuli_contrastSwitching.csv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]
2025-08-15 Remove unused Bonsai workflow files
    Deleted multiple Bonsai workflow and layout files related to FlickerStimulation, Ganzfeld, and LEDstimulation workflows. This cleanup removes obsolete or unused experiment configurations from the rep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
    [dists_contrastSwitching_4_8only.csv, dists_sinewave_contrastTuning.csv, dists_sinewave_highreps.csv]
2025-10-18 Refactor flicker trial extraction and alignment pipeline
    Rewrote getFlickerTrialInfo_dev.m to use a modular, block-based approach for extracting and aligning flicker trials, with improved wheel data alignment and trial property injection. Updated crateTria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
2025-11-14 update driver circuit info
    Removed detailed sections on LED stimulation and driver design from the README.
2025-11-14 Update LED section with new links
    Replaced custom LED PCB link with links to green and UV LEDs.
2025-12-18 Update README with Timer configuration details
    Added future plans for Timer3 and Timer4 configuration.
2025-12-18 Add Performance Characteristics section to README
    Added a new section on Performance Characteristics detailing switching dynamics, linearity, resolution, and thermal stability.
2026-01-04 removed analysis
    [LED_board_humans.kicad_pcb, LED_board_humans.kicad_sch, LED_board_humans.step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]
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2026-03-18 started working on task logic
    click sounds for stim on/off
    [dists_sinewave_test.csv, stimuli_sinewave_test.csv]
2026-03-25 added audio clicks
    [LED_board.stl]
2026-04-02 pre-fix envelope freq issue
    [dist_flickerTask.csv, dist_task.csv, sinenev_40hz.csv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]
2026-04-02 added test panel gamma correction
    [DATA08.CSV]
2026-04-02 gamma retest
    [DATA09.CSV]
2026-04-02 bench supply gc try
    [DATA10.CSV]
2026-04-02 raised cosine contrast envelope
    [dist_flickerTask.csv, stimuli_flickerTask.csv]
2026-04-09 fixed buggy lut on 8bit DDS code
    [StimulusControlViaSerial_Leonardo_DDS_8bit_2freq.ino]
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2026-04-22 updating arduino code
    [dist_flickerTask.csv, envelopeTest.csv, stimuli_flickerTask.csv]
2026-04-22 Optimize LUTs, types, and ISR performance
    Convert 8-bit lookup tables and related pointers to PROGMEM uint8_t to save memory and simplify reads; update pgm_read_* calls accordingly. Replace 32-bit math with 16-/8-bit operations where safe (temp/ocr vars) to reduce overhead. Replace PORTD XOR toggles with PIND writes for single-cycle hardware toggles. Inline and always-inline setChA/setChB to read bytes from PROGMEM. Precompute sweepStepMultiplier and use multiply/divide in FrequencySweep to avoid repeated exp() calls. Minor safety/clarity fixes: initialize serialVals, small formatting tweaks, and a comment noting corrected Timer1 math. These changes target reduced flash/RAM usage and faster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
    [StimulusControlViaSerial_Leonardo_DDS_8bit_2freq.ino]
2026-04-22 Optimize ISR math and reduce LUT size
    Reduce memory and speed up interrupt code: change raisedCosineLUT to uint8_t and scale it 0–255, change contrast scaling from 256->255 across functions, and add a 32-bit fadePhase accumulator to replace costly 32x32 multiplications in ISRs. Apply multiple ISR optimizations: use 32-bit addition for envelope progression, reset fadePhase at fade boundaries, remove unnecessary uint32_t casts, use a little-endian byte-pointer to fetch the top byte of phase accumulators, and simplify arithmetic to 16-bit where safe. Also include small cleanups (comment tweaks, minor whitespace changes) and retain existing functionality while improving performance and reducin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
    [StimulusControlViaSerial_Leonardo_DDS_8bit_2freq.ino]
2026-04-22 perfect frequencies
    Replace expensive 64-bit division in calcPhaseInc with a precomputed float multiplier (137438.953125f) for a faster exact result. Refactor ISR code to use 16-bit arithmetic where safe: cast operands to uint16_t before multiplies to avoid overflow, change intermediate OCR computations to int16_t, remove unnecessary 32/64-bit casts, and keep existing bounds checks. Minor comment and whitespace cleanup. These changes reduce CPU and code-size cost on AVR while preserving behavior.
    [StimulusControlViaSerial_Leonardo_DDS_8bit_2freq.ino]
2026-05-06 manualMethodsOfAdjustent bonsaicode
    [3d_eye_states.csv, blinks.csv, events.csv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]
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2026-05-13 aman testing stim
    [dist_flickerTask22stimuli.csv, stimuli_flickerTask.csv, stimuli_flickerTask300ms.csv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]
2026-05-14 Started work on general task workflow
    [dist_flickerTask.csv, dist_flickerTask22stimuli.csv, dist_task.csv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]
2026-05-15 added Method of constant stimuli
    [SubjectData2026-05-15T09_43_48.csv, SubjectData2026-05-15T09_54_33.csv]
2026-05-15 Added performance visualisers
    [SubjectData2026-05-15T16_34_28.csv]
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2026-06-04 imu tracking data csv
    [imu_walking_test2026-06-04T11_13_04.csv]
2026-06-10 2-interval response for discrim and yes/no
    [imu_walking_test2026-06-04T11_08_49.csv, imu_walking_test2026-06-04T11_12_30.csv, imu_walking_test2026-06-04T11_12_44.csv]
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2026-06-16 Tided up arduino code dir and added new mouse rig dds
    [imu_walking_test2026-06-04T11_13_04.csv]
2026-06-16 stepped freq sweep stimulus for mouse rig
    [dists_steppedFreqSweep.csv, stim_steppedFreqSweep.csv]
2026-06-16 added pupil labs 3d printing files
    [LED_dome.stl, NEON_Bare_Metal_Nest_interface.step, Neon_JAN_frame_reference.iam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]
2026-06-16 reorganise glasses 3d printing files
    [LED_dome.stl, NEON_Bare_Metal_Nest_interface.step, Neon_JAN_frame_reference.iam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]
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
